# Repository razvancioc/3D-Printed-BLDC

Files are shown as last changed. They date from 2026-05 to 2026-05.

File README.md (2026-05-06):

# 3D-Printed-BLDC
# 3D Printed 12N14P BLDC Motor (Work in Progress)





A fully customizable, experimental Brushless DC (BLDC) motor designed to be 3D printed. This project explores the limits of 3D printing in high-RPM applications (up to 20,000 RPM) using a **12N14P** configuration optimized for drones (4S batteries, ~1350 KV). 

*Note: This project is currently under active development and construction.*

---

## Overview

This motor is being designed from the ground up to overcome the classic challenges of 3D-printed motors (e.g., plastic melting, eddy currents, and high-RPM hoop stress). By combining 3D-printed plastic with reinforcement elements (Kevlar/Cyanoacrylate), steel cores (insulated nails) for the stator, and high-quality bearings, the goal is to build a motor capable of delivering real, usable torque.

### Technical Specifications (Target)
* **Configuration:** 12 Stator Teeth / 14 Rotor Poles (12N14P)
* **Target RPM:** 20,000 RPM at 14.8V (4S Battery)
* **Motor Constant (KV):** ~1350 KV
* **Winding Scheme:** dLRK (A-b-C-a-B-c-A-b-C-a-B-c)
* **Windings:** 0.5 mm enameled copper wire (3 strands in parallel per turn), 13 turns/tooth.

---

## Bill of Materials (BOM)

| Component | Specifications / Details | Quantity |
| :--- | :--- | :--- |
| **Magnets** | Neodymium, flat (5x5x1 mm) | 14 pcs |
| **Bearings** | MR84ZZ metal shielded (4x8x3 mm) | 2 pcs |
| **Central Shaft** | Steel / Stainless Steel, 4 mm diameter | 1 pc |
| **Copper Wire** | Enameled, 0.5 mm diameter | ~10 meters |
| **Stator Core** | Thin steel nails (varnish-insulated) | - |
| **Adhesive / Resin** | Loctite 638 (shaft), Epoxy Resin (magnets) | - |
| **3D Parts** | Stator, Rotor (Bell), Base (PETG / ABS / PC) | 1 Set |

---

## Build Log & Assembly (Ongoing)

### 1. 3D Printing the Components
The parts are being printed with strict tolerances in mind. The stator features 4 mm walls for the teeth, and the rotor has an internal 14-sided polygonal profile to ensure a perfectly flat mounting surface for the magnets.

3D Printed Parts
*> Add a picture of the freshly printed Stator and Rotor here.*

### 2. Stator Assembly & Winding
To increase efficiency and reduce overheating, the center of each plastic tooth is filled with steel (varnish-insulated nails). The winding is being done manually following the dLRK scheme. To support currents up to 20A, 3 strands of 0.5 mm wire are routed in parallel.

Wound Stator
*> Add a close-up picture of the copper wound around the stator here.*

### 3. Rotor (Bell) Assembly
The magnets are secured using epoxy resin, strictly following the **North-South** alternating pole rule. The designed pockets allow for a perfect slide-in fit, maintaining a 0.5 - 0.8 mm air gap from the stator.

To prevent the motor from exploding due to centrifugal force (hoop stress), the exterior of the bell will be wrapped in Kevlar thread and sealed with Cyanoacrylate.

Rotor Assembly
*> Add a picture of the inside of the rotor, showing the glued magnets.*

### 4. Final Assembly (Pending)
The 4 mm shaft will be press-fitted into the rotor, passed through the MR84ZZ bearings mounted in the center of the stator, and secured with a C-clip at the bottom.

Assembled Motor
*> Will add a picture of the fully assembled motor here once completed.*

---

## Upcoming Testing & Calibration

Once the build is complete, the following tests will be performed using a standard drone ESC and an optical tachometer:

1. **No-Load KV Test:** Measuring the RPM without a propeller at a known voltage.
2. **Turn Adjustment:** If the RPM differs from the targeted 1350 KV, the number of turns will be adjusted using the calibration equation from the design phase.
3. **Load Test:** Mounting a 6" or 7" propeller and monitoring the stator temperature.

---

## Safety Warning
This motor is designed to reach extremely high speeds (20,000 RPM). A faulty 3D print or weak magnet adhesion can lead to catastrophic rotor failure and disintegration. **Always wear safety goggles during testing and never stand in the rotational plane of the propeller!**

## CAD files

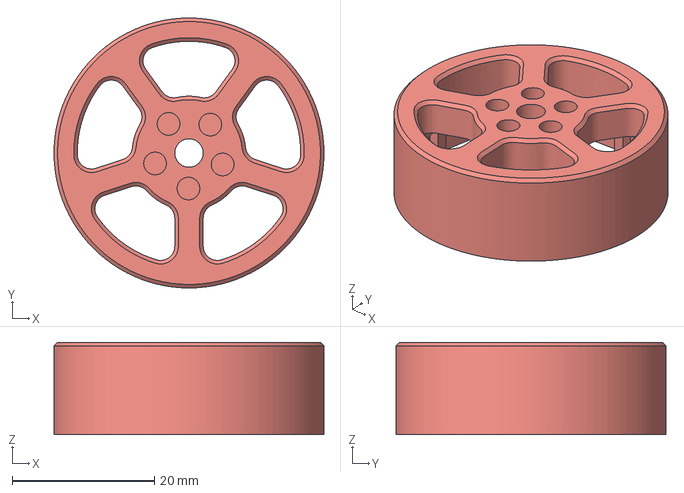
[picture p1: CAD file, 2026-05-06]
CAD/30mm BLDC Rotor.3mf
38.0 x 38.0 x 13.0 mm

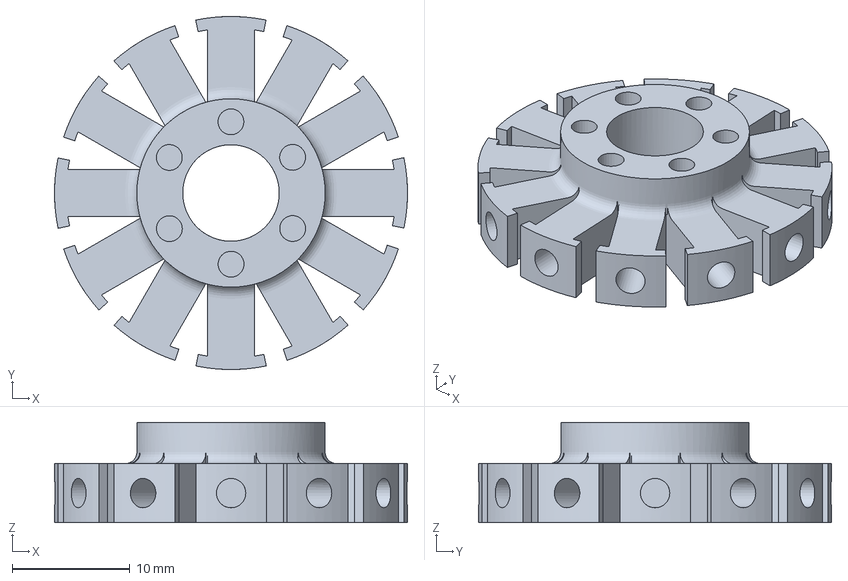
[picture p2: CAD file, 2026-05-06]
CAD/30mm BLDC Stator.3mf
30.0 x 30.0 x 8.50 mm

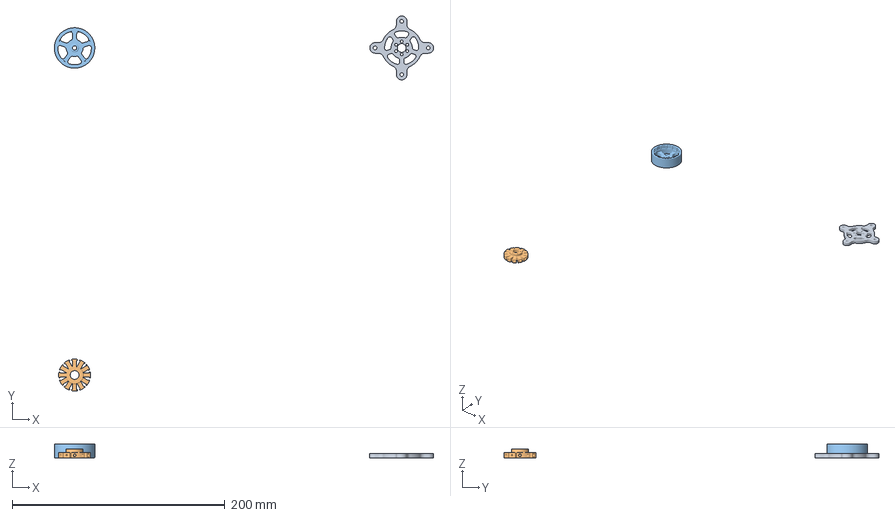
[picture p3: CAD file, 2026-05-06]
CAD/30mm BLDC Stator Base.3mf
356.2 x 352.2 x 13.0 mm

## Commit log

2026-05-06 Rename Rotor BLDC 30mm.3mf to CAD/30mm BDLC Rotor.3mf
    [30mm BDLC Rotor.3mf]
2026-05-06 Rename Baza Stator BLDC 30mm.3mf to CAD/30mm BDLC Stator Base.3mf
    [30mm BDLC Stator Base.3mf]
2026-05-06 Rename Stator BLDC 30mm.3mf to CAD/30mm BLDC Stator.3mf
    [30mm BLDC Stator.3mf]
2026-05-06 Rename 30mm BDLC Stator Base.3mf to 30mm BLDC Stator Base.3mf
    [30mm BLDC Stator Base.3mf]
2026-05-06 Rename 30mm BDLC Rotor.3mf to 30mm BLDC Rotor.3mf
    [30mm BLDC Rotor.3mf]
